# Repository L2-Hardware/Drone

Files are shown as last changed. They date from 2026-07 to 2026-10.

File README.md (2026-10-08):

# Drone

# Custom 5-Inch Quadcopter Project

Welcome to the main repository of our custom-built 5-inch FPV drone. This project is a collaborative effort to design, build, and program a high-performance quadcopter completely from scratch, bridging custom mechanical engineering with bespoke hardware and software design.

## Project Overview

Instead of relying on off-the-shelf Flight Controllers (FC) or pre-compiled firmware like Betaflight/ArduPilot, this project aims to build the core systems from the ground up to deeply understand drone flight dynamics, sensor fusion, and real-time embedded systems.

The project is divided into three main domains:
*   **Mechanics & Frame:** Custom 5-inch carbon fiber frame designed from scratch (designed by [Friend's Name]).
*   **Hardware (FC PCB):** A custom-designed Flight Controller board based on the STM32 architecture.
*   **Firmware (MCU):** A custom RTOS-based flight control software written in C/C++.

## System Architecture

*   **Power & Propulsion:** 6S LiPo Battery, custom 4-in-1 ESC (`Hardware/Kicad/ESCV00`, AM32 firmware), and 4x Brushless Motors (2207/2306).
*   **Radio Control:** custom ExpressLRS (ELRS) 2.4GHz receiver (`Hardware/Kicad/RXV00`, ESP32-C3 + SX1281) communicating via CRSF protocol for ultra-low latency.
*   **Video System (FPV):** custom analog 5.8GHz VTx (`Hardware/Kicad/VTXV00`, RTC6705 + RFPA5542) with on-board OSD (AT7456E) on the FC.
*   **Brain:** Custom STM32 Flight Controller (See `/Hardware` and `/Firmware` folders).

## Repository Structure

*   `/Mechanics` - 3D models, CAD files, and CNC routing paths for the frame.
*   `/Hardware` - KiCad projects: flight controller (FCV00), 4-in-1 ESC (ESCV00), ELRS receiver (RXV00), video transmitter (VTXV00).
*   `/Firmware` - STM32 source code, RTOS configuration, and PID algorithms.

## Status
*Active Development* - Currently designing the FC PCB and prototyping the RTOS task scheduler.

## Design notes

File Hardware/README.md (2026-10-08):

# Drone

# Custom Flight Controller PCB

This directory contains the KiCad projects for all the drone electronics, designed at chip level (no plug-and-play modules):

*   `Kicad/FCV00` - Flight Controller
*   `Kicad/ESCV00` - 4-in-1 ESC (AM32)
*   `Kicad/RXV00` - ExpressLRS 2.4 GHz receiver
*   `Kicad/VTXV00` - 5.8 GHz analog video transmitter

See `Kicad/Readme.md` for the block diagram, component choices, library installation and the list of items to verify before ordering boards.

The flight controller specifications are below.

## Hardware Specifications

*   **Form Factor:** 30.5 x 30.5 mm mounting pattern (Standard 5-inch stack).
*   **Microcontroller:** STM32F405RGT6 (168 MHz Cortex-M4F, 1 MB flash).
*   **IMU (Gyro/Accel):** TDK InvenSense ICM-42688-P on a dedicated **SPI1** bus with its own LDO and external 32 kHz CLKIN.
*   **Barometer:** ST LPS22DF (I2C1).
*   **Blackbox:** Winbond W25Q128JV 16 MB SPI flash (SPI3).
*   **OSD:** AT7456E chip on SPI2 for analog video telemetry overlay.
*   **Power Supply (BEC):** 
    *   Input: 6S LiPo (up to 25.2V).
    *   Step-down buck converters (TI TPS54360B, 60 V rated): 5V/3A (ELRS Rx, VTx, GPS, LEDs, USB) and 10V/2A (camera / HD VTx).
    *   3.3V: two AP2112K LDOs from 5V (one dedicated to the IMU).

## Pinout & Connectivity

The PCB is designed with the following I/O in mind:
*   **8-pin ESC Connector:** Carries GND, VBAT (Input), Current Sensor (ADC in), and 4x Motor Signals (DShot/PWM out).
*   **UART 1:** ExpressLRS Receiver (CRSF Protocol).
*   **UART 2 / SPI:** Video Transmitter (VTx) control / OSD.
*   **UART 3:** GPS / Compass (for future expansions).
*   **UART 4 / UART 5 TX:** AUX port.  **UART 5 RX:** ESC telemetry.
*   **USB-C:** configuration and DFU (BOOT button).
*   **I2C:** Reserved for external barometers or slow sensors.

## Design Considerations
*   **EMI Shielding:** The IMU is placed away from high-current ESC traces to minimize electromagnetic interference.
*   **Vibration Isolation:** The board must be mounted using rubber dampeners (gummies) to protect the gyro from motor noise.
*   **Decoupling:** Ample decoupling capacitors are placed near the STM32 and IMU to ensure clean power delivery.

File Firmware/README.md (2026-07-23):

# Drone

# Flight Controller Firmware

This directory contains the custom flight control software running on the STM32 microcontroller. The firmware is built around **FreeRTOS** to ensure strict deterministic execution of the critical flight loop while handling slower background tasks like telemetry and RC link parsing.

## Core Architecture (FreeRTOS)

To prevent communication protocols from blocking the flight stabilization, the firmware is divided into prioritized RTOS tasks:

1.  **High-Priority Flight Loop (1kHz - 4kHz):** 
    *   Reads IMU data via SPI.
    *   Applies Digital Low-Pass & Notch Filters to remove motor vibration noise.
    *   Computes Attitude Estimation (Mahony/Madgwick quaternion filters).
    *   Calculates the PID control output for Roll, Pitch, and Yaw.
    *   Mixes outputs and sends DShot commands to the 4-in-1 ESC.
2.  **Medium-Priority RC Task (250Hz / 500Hz):** 
    *   Parses incoming CRSF packets from the ExpressLRS receiver via UART.
    *   Maps stick inputs to desired angles/rates.
3.  **Low-Priority Telemetry & Video Task (10Hz):** 
    *   Reads battery voltage and current consumption.
    *   Sends record Start/Stop commands to the FPV camera.
    *   Updates OSD data.

## Flight Dynamics

*   **Attitude Estimation:** Fusing accelerometer and gyroscope data to calculate the drone's absolute orientation in 3D space.
*   **PID Controller:** Custom Proportional-Integral-Derivative loops tuned for 5-inch freestyle/racing dynamics.
*   **Motor Protocol:** Utilizing **DShot600** (Digital Shot) to send precise, noise-free throttle values to the ESC.

## Development Setup

*   **Toolchain:** GCC ARM Embedded / STM32CubeIDE.
*   **HAL:** STM32 Hardware Abstraction Layer (HAL) / LL drivers.
*   **RTOS:** FreeRTOS (CMSIS-V2).

### How to Build
1. Clone the repository.
2. Open the `.ioc` file in STM32CubeMX / STM32CubeIDE.
3. Generate code and compile using the standard ARM GCC toolchain.
4. Flash via ST-Link using SWD interface.

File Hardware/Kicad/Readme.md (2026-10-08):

# KiCad projects - drone electronics

## Libraries

All projects use the official library **[L2-Hardware/Kicad_Libs](https://github.com/L2-Hardware/Kicad_Libs)**
through the folder `Hardware/Kicad/KiCad_Libs` (ignored by git). The projects' `sym-lib-table` / `fp-lib-table`
point to `${KIPRJMOD}/../KiCad_Libs/<eLib>/...`.

Setup (once per PC):

```
cd C:\git\PCB
git clone https://github.com/L2-Hardware/Kicad_Libs.git      (-> C:\git\PCB\Kicad_Libs)
cd C:\git\PCB\Drone\Hardware\Kicad
bring_libs.bat                                                  (junction KiCad_Libs -> C:\git\PCB\Kicad_Libs)
```

### Adding new components: `KiCad_Libs_ToAdd/`

New parts that are not yet in the official library go into `KiCad_Libs_ToAdd/`, using the same layout
(`<eLib>/datasheet`, `<eLib>.3dshapes`, `<eLib>.pretty`, `<eLib>.kicad_sym` with only the new symbols).

1. `merge_libs.bat --clean`
   - appends the new symbols to `KiCad_Libs/<eLib>/<eLib>.kicad_sym` (a `.bak` is kept; existing names are skipped)
   - copies footprints, STEP models and datasheets (existing files are not overwritten, unless `--force`)
   - empties `KiCad_Libs_ToAdd` (only its README stays)
2. Open the touched libraries once in the Symbol Editor and save (upgrades them to your KiCad version),
   delete the `.bak` files, then commit + push in `C:\git\PCB\Kicad_Libs`.
3. Commit the emptied `KiCad_Libs_ToAdd` in this repo.

The schematics and PCBs embed their symbols and footprints, so they open even before the merge;
3D models (`${KIPRJMOD}/../KiCad_Libs/<eLib>/<eLib>.3dshapes/...`) show once the parts are in the official library.

Current content of `KiCad_Libs_ToAdd` (drone boards): footprints and 3D models from the official KiCad libraries,
symbols generated from the KiCad symbol pin tables where available, otherwise from the vendor datasheet
(those carry a `Verify` field). It also contains generic symbols (`R`, `C`, `L`, `LED`, power symbols ...):
if the official library already has symbols with the same names they are skipped by the merge.

## Boards

| Project | Board | Size / layers | Main parts |
|---|---|---|---|
| `FCV00` | Flight controller | 36x36 mm, 30.5 mm M3 pattern (4 mm holes for grommets), 4 layers | STM32F405RGT6, ICM-42688-P, LPS22DF, AT7456E OSD, W25Q128JV, 2x TPS54360B (5V 3A / 10V 2A), 2x AP2112K-3.3, USB-C |
| `ESCV00` | 4-in-1 ESC (AM32) | 42x42 mm, 30.5 mm M3 pattern, 6 layers 2 oz recommended | 4x (STM32F051K8U6 or AT32F421K8U7 + DRV8300D + 6x BSZ018N04LS6), 0.25 mOhm shunt + INA181A3, LMR16006 10V gate rail |
| `RXV00` | ExpressLRS 2.4 GHz receiver | 22x14 mm, 4 layers | ESP32-C3FH4 + SX1281, u.FL |
| `VTXV00` | 5.8 GHz analog VTX | 27x27 mm, 20x20 mm M2 pattern, 4 layers | RTC6705 + RFPA5542 (~25 dBm), STM32F031G6U6 / GD32F130G6U6 (OpenVTx) |

```
 6S LiPo ──XT60──► ESCV00 ──(JST-SH 8: VBAT GND CURR TLM M1..M4)──► FCV00 ──(JST-SH 4: 5V GND TX RX)──► RXV00 ── 2.4 GHz antenna
                   │  4x BLDC motors                                  │  ├─(JST-SH 6: 10V 5V GND VIDEO TX RX)──► VTXV00 ── 5.8 GHz antenna
                   └──────────────────────────────────────────────────┘  ├─(JST-SH 3: PWR GND VIDEO)◄── analog FPV camera (bought)
                                                                         ├─ GPS / compass port, AUX UART port, LED strip, buzzer
                                                                         └─ USB-C (configuration / DFU)
```

The connectors are pin-matched, so the harnesses are 1:1 JST-SH cables. Power the FC from the ESC harness only,
not from separate battery wires. Otherwise part of the motor return current flows through the JST ground wire
and bypasses the current shunt.

Bought parts that are not designed here: motors, battery, camera, propellers, antennas, frame.

### Each project contains
* `<NAME>.kicad_sch` - hierarchical schematic (root page = overview + design notes, one sub-sheet per block)
* `<NAME>.kicad_pcb` - board outline, mounting holes, layer count, GND plane on In1, every footprint loaded with
  its nets and linked to its symbol (footprints are parked next to the outline, grouped by sheet)
* `<NAME>.kicad_pro` - net classes (power / gate / RF 50 ohm / USB ...) and JLCPCB-compatible minimum rules
* `<NAME>_BOM.csv` - grouped BOM with manufacturer part numbers for the active parts
* `RXV00/RXV00_hardware.json` - ExpressLRS hardware layout for the receiver

## Validation done
* Every schematic was exported with `kicad-cli`. KiCad's connectivity matches the intended netlist exactly (no
  merged or split nets).
* Every symbol pin maps to a footprint pad. Every footprint pad that needs a net has one.
* All symbol libraries load in KiCad.
* Files are written in the KiCad 7 format. KiCad 8/9 open them and upgrade them on save. Run ERC in KiCad once
  after opening: the KiCad 7 command line has no ERC.

## Verify before ordering boards
Parts whose pin table was typed from a datasheet carry a `Verify` field. Check them against the latest datasheet:

| Part | What to check |
|---|---|
| AT7456E | Uses the MAX7456 pinout. Check the HTSSOP exposed-pad size. |
| SX1281 | Pin table from Semtech DS rev 3.x. RF matching values are starting points (tune with a VNA). |
| RTC6705 | Pin table from `datasheet/RTC6705-RichWave.pdf`. The exposed-pad size is not given (QFN-40 6x6, EP 4.6 assumed). Loop filter, output match and the BUFVDD power-control path are starting points. |
| DRV8300DRGER | Pin table from the TI datasheet. Check the RGE exposed-pad size. |
| ICM-42688-P | Pin table from the KiCad IIM-42652 symbol (same LGA-14 package). Check the RESV pins. |
| BSZ018N04LS6 | NexFET SON3.3 land pattern reused. Compare with Infineon's PG-TSDSON-8 FL footprint. |
| TPS54360B | The compensation network is a starting point. Run TI WEBENCH for the final values. |

Passive, crystal and LED part numbers are suggestions: confirm them (stock, load capacitance, voltage rating) at
your distributor or assembler.

## Next steps
1. Merge `KiCad_Libs_ToAdd` into the official library (above), open each project, run ERC.
2. PCB: place the parts (connectors on the edges, IMU away from the bucks, short power loops), then route.
   Use 50 ohm coplanar lines on RXV00/VTXV00 and a full GND plane under the RF parts. On ESCV00, use wide
   polygons for VBAT/phases and thermal vias. Run DRC.
3. Order from JLCPCB / PCBWay: gerbers + BOM + placement file, assembly (ESC 6 layers 2 oz).
4. Bring-up order: power rails, then SWD/DFU, then each sensor, then radio links.

## Firmware notes
* **FCV00**: pin map on the root sheet (gyro SPI1 + external 32 kHz CLKIN on PB0, OSD SPI2, flash SPI3,
  motors TIM8 CH1-4 on PC6-PC9).
* **ESCV00**: AM32. With F051, use `HARDWARE_GROUP_F0_B`. With AT32F421, use `HARDWARE_GROUP_AT_B` +
  `HARDWARE_GROUP_AT_045` (same pinout as `TBS_6S_4IN1_F421`). Flash the bootloader per MCU through the SWD pads
  once.
* **RXV00**: ExpressLRS `Unified_ESP32C3_2400_RX` + `RXV00_hardware.json` (based on "Generic C3 2400").
* **VTXV00**: OpenVTx `Generic_GD32F130` pinout (populate GD32F130G6U6), or your own firmware on the STM32F031.
  Up to 25 mW EIRP is licence-free in the EU. Higher power needs an amateur radio licence.

## Regenerating
`tools/gen/` holds the scripts that produced the `KiCad_Libs_ToAdd` parts, schematics, BOMs and PCB set-up:
`build.py` (libraries + schematics + BOM), `check.py` (connectivity check) and `pcbgen.py` (PCB set-up).
**Re-running them overwrites the project files.** They are a starting point: once you start editing in KiCad,
KiCad is the master.

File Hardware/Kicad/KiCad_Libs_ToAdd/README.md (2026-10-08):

# KiCad_Libs_ToAdd

Inbox for new components that are not yet in the official library
([L2-Hardware/Kicad_Libs](https://github.com/L2-Hardware/Kicad_Libs)).

Same layout as the official library:

```
<eLib>/
    datasheet/
    <eLib>.3dshapes/
    <eLib>.pretty/
    <eLib>.kicad_sym      only the new symbols
    .gitignore
```

Workflow:
1. `bring_libs.bat` (once): junction `KiCad_Libs` -> `C:\git\PCB\Kicad_Libs`
2. `merge_libs.bat --clean`: merges everything here into the official library and empties this folder
3. Open the touched libraries in the Symbol Editor, save, then commit + push in the `Kicad_Libs` repo
4. Commit the (now empty) `KiCad_Libs_ToAdd` here

Usually this folder is empty (only this README).

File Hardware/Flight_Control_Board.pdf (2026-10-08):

## Flight Controller Board HARDWARE ARCHITECTURE

Lorenzo Bartalucci

1

1 INTRODUCTION

### 1 Introduction

### 1.1 Purpose and Scope

This document defines the hardware architecture, component selection rationale, power distribution network (PDN) design, signal integrity (SI) rules, RF subsystem design, electromagnetic compatibility (EMC) strategy, mechanical/DFM constraints, and verification plan for the HRO-FC1 — a custom flight controller (FC) intended for a multirotor aerial observation platform requiring simultaneous 4 K on-board video recording and low-latency analog FPV downlink with remote camera tilt control.

This specification is the authoritative reference for PCB layout, component procurement, and verification test planning. It supersedes the informal concept notes captured in Rev. A.

### 1.2 Applicable Documents and Standards

- IPC-2221 — Generic Standard on Printed Board Design
- IPC-2141A — Design Guide for High-Speed Controlled Impedance Circuit Boards
- IPC-6012 — Qualification and Performance Specification for Rigid PCBs (Class 2 target, Class 3 workmanship where noted)
- IPC-A-610 — Acceptability of Electronic Assemblies
- FCC Part 15, Subpart C (§15.247 / §15.249) — Intentional radiators, 5.725–5.875 GHz ISM band
- ETSI EN 300 440 — Short-range devices, 5.8 GHz band (EU applicability)
- MIL-STD-810H, Method 514.8 — Vibration (Category 24, rotary-wing platform, as guidance only; full military qualification is out of scope)
- RTCA DO-160 (referenced for environmental test methodology guidance only; full DO-160 qualification not required for this program)

### 1.3 Definitions and Acronyms

Term | Definition
FC | Flight Controller
PDN | Power Distribution Network
PDS | Power Distribution System (synonymous with PDN in this document)
SI | Signal Integrity
CPWG | Coplanar Waveguide with Ground
VTx | Video Transmitter (analog, 5.8 GHz)
PA | Power Amplifier
IMU | Inertial Measurement Unit
CVBS | Composite Video Baseband Signal (analog composite video)
DFM/DFA | Design for Manufacturing / Design for Assembly
FMEA | Failure Modes and Effects Analysis
EIRP | Effective Isotropic Radiated Power
ESR/ESL | Equivalent Series Resistance / Equivalent Series Inductance

### 1.4 Mission Profile / Concept of Operations

The vehicle is a hexacopter observation platform performing loiter/hover observation at 30 m to 120 m AGL for missions up to 25 minutes on 6S LiPo. The system must simultaneously: (a) record 4 K @ 30 fps to onboard storage for post-mission analysis, (b) provide a real-time analog FPV downlink to the ground pilot/observer for situational awareness, and (c) allow the observer to remotely pitch the camera between −90◦

(nadir) and +30◦
from level. Altitude hold via barometer

1 INTRODUCTION

and GPS position hold are required to keep the platform stable while the observer manually operates the gimbal, decoupling flight control workload from camera aiming workload.

### 2 System Requirements

Requirements are numbered for traceability into the Verification Matrix (Section 13). “Shall” denotes a mandatory, testable requirement; “should” denotes a goal.

### 2.1 Functional Requirements

ID | Requirement
REQ- CAM-001 | The system shall record video at 4 K (3840×2160) at 30 fps to remov- able Micro SD storage, U3/V30 rated, up to 128 GB.
REQ- CAM-002 | The system shall provide a simultaneous real-time analog CVBS output (NTSC or PAL, field-selectable) for the FPV downlink, independent of the SD recording pipeline.
REQ- CAM-003 | The FC shall be able to start/stop SD card recording via a UART command link to the camera module, triggered by a radio control (RC) auxiliary channel.
REQ- GIM-001 | The FC shall generate a servo-compatible PWM signal (50 Hz nominal, 1000 µs to 2000 µs pulse width) on a hardware timer channel to actuate a camera tilt servo across a minimum mechanical range of 120◦
REQ- GIM-002 | Loss of RC signal shall command the gimbal to a pre-configured safe position (default: level, 0
◦
) within 500 ms of failsafe detection.
REQ- VTX-001 | The onboard VTx shall be tunable in firmware across the standard 5.8 GHz analog FPV band plan (Section 9) via SPI, with the active channel persisted in non-volatile memory.
REQ- VTX-002 | The VTx output power shall be configurable to at least three discrete levels (nominal targets: 25 mW, 200 mW, 400 mW) to support regional regulatory compliance.
REQ- NAV-001 | The FC shall maintain barometric altitude hold to within ±0.5 m in still air and provide GPS-based position hold to within ±1.5 m horizontal (with ≥8 satellites, HDOP < 1.5).
REQ- NAV-002 | Compass (magnetometer) heading accuracy shall be within ±5
- post-
| calibration, with the module physically separated from high-current conductors per Section 10.

### 2.2 Performance Requirements

ID | Requirement
REQ- PERF-001 | Glass-to-glass analog FPV latency shall not exceed 80 ms (camera sen- sor to ground-station display), excluding goggle/receiver processing.
REQ- PERF-002 | IMU sampling rate shall be ≥6.4 kHz raw, with attitude control loop closure at ≥2 kHz to support stable hover in gusts up to 8 m/s.
REQ- PERF-003 | VTx analog video downlink range (line-of-sight, 400 mW, standard patch/omni antenna) shall achieve ≥2 km at ≤−85 dBm receiver sen- sitivity margin of 6 dB.

2.3 Environmental Requirements | 1 INTRODUCTION
ID | Requirement
REQ- PERF-004 | Total continuous current draw of the FC/camera/VTx/gimbal subsys- tem (excluding motors/ESCs) shall not exceed 3.0 A at 5 V, per the power budget in Table 11.

### 2.3 Environmental Requirements

ID | Requirement
REQ- ENV-001 | Operating temperature range: −10◦C to +45◦C ambient; storage −20◦C to +60◦C.
REQ- ENV-002 | The PCB assembly shall withstand random vibration per MIL-STD- 810H Method 514.8, Category 24 (rotary-wing, general), 7.7 grms, 10 Hz to 2000 Hz, without component detachment or solder joint fatigue over a 2-hour per-axis test.
REQ- ENV-003 | The assembly shall tolerate humidity up to 95% RH non-condensing; conformal coating is required per Section 11.
REQ- ENV-004 | Operating altitude up to 4000 m MSL (derate convective cooling as- sumptions accordingly, see Section 6.3).

### 2.4 EMC / Regulatory Requirements

ID | Requirement
REQ- EMC-001 | The VTx intentional radiator shall comply with FCC Part 15.247 (or region-appropriate equivalent, e.g., ETSI EN 300 440) for the target market at the configured output power level.
REQ- EMC-002 | Radiated/conducted emissions from the RF section shall not desen- sitize the IMU, barometer, GPS L1 front-end (1575.42 MHz), or the analog CVBS trace by more than 1 dB / 1 LSB equivalent noise floor increase, verified per Section 10.
REQ- EMC-003 | Regulatory caution: 400 mW EIRP exceeds unlicensed limits in sev- eral jurisdictions (e.g., EU 25 mW under ETSI EN 300 440 for non- amateur use). The design shall default to the lowest legal power level in firmware and require explicit user configuration to enable higher power modes, with an on-screen/telemetry regulatory disclaimer.

### 2.5 Safety Requirements

ID | Requirement

REQ-SAF-

001 | Input power path shall include reverse-polarity protection, input fus- ing/current limiting, and inrush current limiting for hot-plug of a charged 6S pack (Section 6).

REQ-SAF-

002 | The MCU shall monitor input bus voltage and enter a low-power/land- now telemetry state below 19.8 V (3.3 V/cell) to protect the LiPo pack.

REQ-SAF-

003 | Thermal protection: firmware shall throttle or disable the VTx PA if the PA case temperature (via NTC or PA internal flag) exceeds 95◦C.

4 CAMERA & GIMBAL SUBSYSTEM DESIGN

### 3 System Architecture Overview

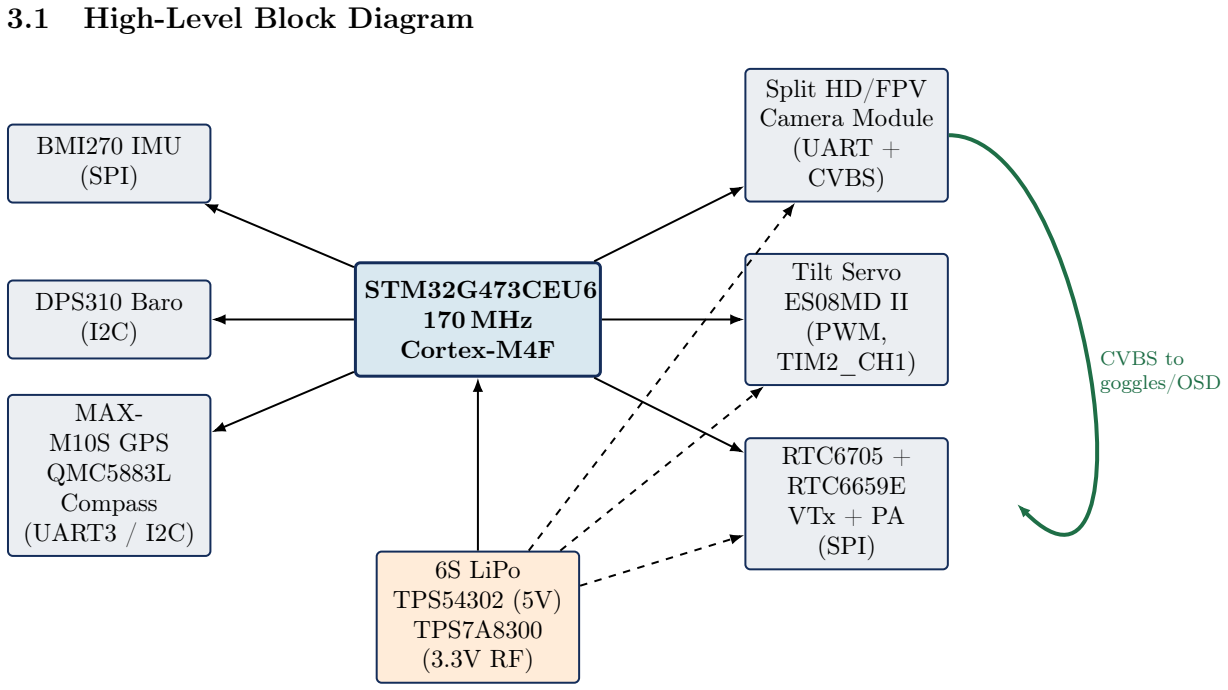
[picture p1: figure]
3.1 High-Level Block Diagram; STM32G473CEU6 170 MHz Cortex-M4F; BMI270 IMU (SPI); DPS310 Baro (I2C); MAX- M10S GPS QMC5883L Compass (UART3 / I2C); Split HD/FPV Camera Module (UART + CVBS); Tilt Servo ES08MD II (PWM, TIM2_CH1); RTC6705 + RTC6659E VTx + PA (SPI); 6S LiPo TPS54302 (5V) TPS7A8300 (3.3V RF); CVBS to goggles/OSD

Figure 1: HRO-FC1 top-level hardware block diagram. Solid arrows: control/data signals. Dashed arrows: power rails. Green: analog video signal path, isolated from the digital control path per Section 10.

### 3.2 Interface Control Summary

### 4 Camera & Gimbal Subsystem Design

### 4.1 Camera Selection Rationale

A split-style HD/FPV camera decouples 4 K ISP/encode workload from the flight-critical STM32, which only needs to arbitrate a UART control link and, optionally, overlay OSD data onto the CVBS path. This avoids adding an application-processor-class SoC (and its associated Linux/RTOS complexity, boot time, and thermal load) to a safety-relevant flight control board.

Design Note — SD Card Selection: Micro SD cards shall be U3/V30 (or A2 where the camera ISP supports it) rated to sustain the ≥30 MB/s minimum write throughput required for stable 4 K@30 H.264/H.265 encoding without frame drops. Industrial-temperature-rated cards (rated to at least the −10◦C to +45◦C operating range of REQ-ENV-001) are recommended over consumer-grade cards, which are frequently only rated to 0

◦C at the low end.

### 4.2 Gimbal Torque Budget

The tilt servo must overcome the gravitational moment of the camera/lens assembly about the tilt axis plus dynamic (vibration/maneuvering) loads. A first-order sizing calculation:

Assumed camera + mount mass, m = 25 g = 0.025 kg
Moment arm (CG offset from tilt axis), r = 20 mm = 0.02 m Static gravitational torque, τg = m · g · r = 0.025 × 9.81 × 0.02 ≈ 4.9 × 10⁻³ N · m ≈ 0.05 kg · cm

4.3 Edge Cases and Fault Handling | 4 CAMERA & GIMBAL SUBSYSTEM DESIGN
Interface | Peripheral | Electrical | Notes
IMU | BMI270 | SPI1, 3.3 V, up to 10 MHz | Dedicated CS,
| | | no bus sharing
| | | with RTC6705
Barometer | DPS310 | I2C1, 3.3 V, 400 kHz | Shares I2C bus
| | | with compass
| | | (different
| | | addresses)
GPS | MAX-M10S | UART3, 3.3 V, 115200 bps (config) | PPS input to
| | | MCU timer
| | | capture for time
| | | sync
Compass | QMC5883L | I2C1, 3.3 V, 400 kHz | Located ≥25 mm
| | | from
| | | PA/inductors
| | | (Section 10)
Camera control | RunCam Split 4 V3 | UART2, 3.3 V TTL, 115200 bps | RunCam Device
| | | Protocol
| | | (start/stop rec,
| | | OSD, mode)
Camera video | RunCam Split 4 V3 | CVBS, 1 Vpp into 75 Ω | Routed as
| | | controlled-
| | | impedance
| | | analog trace to
| | | VTx and to an
| | | external
| | | OSD/goggle
| | | pigtail
Gimbal servo | EMAX ES08MD II | PWM, TIM2_CH1, 3.3 V logic / 5 V supply | Update rate
| | | 50 Hz, resolution
| | | ≥ 10-bit
| | | equivalent
VTx control | RTC6705 | SPI2, 3.3 V, ≤1 MHz | Register-based
| | | PLL frequency +
| | | power level set
Battery sense | — | Analog, resistor-divided to ≤3.3 V | ADC1, hardware
| | | low-pass at 10 Hz

Table 7: Interface Control Document (ICD) summary. Full pin mapping in Appendix A.

Adding a dynamic safety factor of 6× (to cover angular acceleration during rapid tilt commands, in-flight vibration coupling, and worst-case CG offset with an accessory such as an IR filter or larger lens) gives a required stall torque of approximately 0.3 kg · cm. The specified EMAX ES08MD II (rated ∼2.0 kg cm at 4.8 V) provides a design margin in excess of 6× over this budget, which comfortably covers gust-induced disturbance torques not captured in the first-order model above.

Design Note — Servo Refresh Rate vs. Control Loop: The gimbal PWM update (50 Hz) is intentionally decoupled from the 2 kHz+ attitude control loop (REQ-PERF-002). The MCU shall write the target pulse width into a double-buffered compare register (TIM2_CH1 CCR, using the timer’s preload feature) so that updates take effect only at the next PWM period boundary, preventing partial-pulse glitches that could cause servo jitter.

### 4.3 Edge Cases and Fault Handling

4.3 Edge Cases and Fault Handling | 4 CAMERA & GIMBAL SUBSYSTEM DESIGN
Candidate | 4K Recording | Analog Latency | Notes
RunCam Split 4 V3 (baseline) | 4K@30, 2.7K@60 | ∼40 ms typical | Mature UART
| | | control protocol
| | | (RunCam Device
| | | Protocol); wide
| | | community/firmware
| | | support.
Caddx Loris 4K | 4K@30, 4K@60
| (HFR) | ∼45–50 ms | Higher headline
| | | resolution/frame-
| | | rate options; verify
| | | UART control
| | | command set parity
| | | before substitution.
Foxeer Mix 2 | 4K@30 | ∼40 ms | Similar form factor;
| | | alternate second
| | | source.

Table 8: Camera module trade study. RunCam Split 4 V3 selected as primary; Caddx Loris 4K retained as approved alternate pending UART command-set validation.

Edge Case | Required Handling
SD card full | Camera module shall report status via UART telemetry (RunCam Device Protocol status field); FC shall raise an
| OSD/telemetry warning at ≥90% capacity and on write
| failure. Recording of flight-critical telemetry (if overlaid)
| must not depend on SD card health.
SD card write corruption on power loss
| A minimum 470 µF (bulk, Section 6) plus internal camera-
| module hold-up capacitance must sustain the camera’s 3.3 V/5 V rail for ≥50 ms after main bus brown-out to allow
| the camera’s internal file system to close the current video segment/finalize the container (MP4 moov atom). This
| shall be validated per test VER-PWR-03.
Camera module brown-out / no ACK on UART
| FC firmware shall implement a 3-retry UART handshake
| with 200 ms timeout before flagging a CAM_FAULT sta-
| tus; VTx CVBS path is unaffected since it is a separate
| analog output not gated by UART link health.
Servo mechanical stall
(ice, physical obstruction, wiring snag)
| FC shall monitor servo supply current via a low-side shunt
| on the dedicated servo rail; sustained current >1.2 A for
| >200 ms shall trigger a GIMBAL_STALL flag and com-
| mand PWM to the neutral position to avoid burning out
| the servo winding.
RC link loss during active tilt command
| Per REQ-GIM-002, revert to configured safe position
| within 500 ms; do not freeze at last commanded angle, since an extreme nadir/zenith angle could obstruct antenna line-
| of-sight to the VTx patch antenna.
Sustained | 4K@30
recording | thermal
throttle | Camera modules are known to throttle bitrate/frame rate
| after ∼10–15 minutes of continuous 4K recording in en-
| closed housings. Provide a minimum 3 mm ventilation gap
| or thermal pad from the camera processing board to the
| airframe shell; this is a mechanical integration note for the vehicle housing design, tracked as open item OPEN-01 (Sec-
| tion 15).

6 POWER ARCHITECTURE & POWER INTEGRITY (PI)

### 5 Bill of Materials & Component Selection

Subsystem | Part Number | Mfr. | Package | Role / Selection Rationale
MCU | STM32G473CEU6 | STMicro. | UFQFPN48 | 170 MHz Cortex-M4F, FPU + CORDIC +
| | | | FMAC, 6× 16-bit advanced timers for
| | | | PWM/servo/ESC generation, hardware CRC
| | | | for SD/telemetry integrity checks.
IMU | BMI270 | Bosch | LGA-14 | Best-in-class vibration rejection (on-chip
| | | | anti-aliasing, low-power high-performance
| | | | modes); SPI up to 10 MHz.
Barometer | DPS310 | Infineon | LGA-8 | High resolution (±0.06 hPa RMS), low
| | | | temperature coefficient, I2C/SPI selectable.
GPS | MAX-M10S | u-blox | LGA-18 | Multi-constellation
| | | | (GPS/GLONASS/Galileo/BeiDou), integrated
| | | | 10 Hz nav solution, dedicated PPS output.
Compass | QMC5883L | QST | LGA-16 | Low-cost 3-axis magnetometer; must be
| | | | physically separated from ESC/PA current
| | | | loops – see Section 10.
VTx core | RTC6705 | RichWave | QFN-32 | Integrated 5.8 GHz FM modulator/PLL
| | | | synthesizer, SPI-programmable channel and
| | | | power.
RF PA | RTC6659E | RichWave | QFN-16 | Boosts RTC6705 output to ∼400 mW EIRP
| | | | class; requires dedicated thermal via array
| | | | (Section 11).
Main buck | TPS54302DDCR | TI | SOT23-
| | | thin/SON-8

Steps 6S (19.8–25.2 V) to 5 V/3 A for camera,
| | | | servo, digital rail source.
RF LDO | TPS7A8300ARGR | TI | VQFN-20 | Ultra-low-noise (9 µVrms typ.), high PSRR
| | | | LDO for RTC6705/PA analog supply.
Digital LDO | (TBD, | e.g.,
| TLV75533)
TI | (pro-
| | posed) | SOT23-5 | Dedicated 3.3 V rail for MCU/IMU/baro/GPS,
| | | | isolated from RF and servo transients; open
| | | | selection, see OPEN-02.
Gimbal servo | ES08MD II | EMAX | — | 9 g metal-gear digital servo, ∼2.0 kg cm stall
| | | | torque at 4.8 V (see Section 4.2 torque budget).
Camera | mod-
ule | RunCam Split 4 V3 | RunCam | — | Split lens/processing architecture; 4K@30 SD
| | | | recording + CVBS output + UART control
| | | | (Section 4.1).

Table 10: Bill of Materials – key active components. Passive component BOM (decoupling, filtering) is enumerated in Table 12. Full BOM with distributor part numbers, unit cost, and lead time is maintained in the companion procurement spreadsheet (out of scope for this document).

△ Caution — Second-Sourcing: The RTC6705/RTC6659E pairing and the TPS7A8300 are specified as single-source in this revision. Given global passive/RF-IC supply volatility, a second-source RF chipset (e.g., IRC Tramp-compatible modules) should be evaluated before committing to tooling; this is tracked as OPEN-03.

### 6 Power Architecture & Power Integrity (PI)

### 6.1 Power Budget

### 6.2 Power Tree

### 6.3 Buck Converter Design (TPS54302, 5 V/3 A)

Assume a representative switching frequency fsw = 570 kHz (typical of this converter class) and a target inductor ripple current of 30% of full load (∆IL = 0.9 A):

L =

(Vin,max − Vout) · Vout

Vin,max · fsw · ∆IL

=

(25.2 − 5.0) × 5.0
25.2 × 570,000 × 0.9

≈ 7.8 µH

A standard 10 µH, shielded-drum inductor rated ≥4.5 Asat is selected to provide margin. Duty cycle at nominal/extreme input:

Dnom =

5.0
22.2

≈ 22.5%, Dmin,V in =

5.0
25.2

≈ 19.8%, Dmax,V in =

5.0
19.8

≈ 25.3%

6.4 PDN Target Impedance | 6 POWER ARCHITECTURE & POWER INTEGRITY (PI)
Load | Rail | Typ. I | Max. I | Typ. P | Max. P
STM32G473 (core+IO) | 3.3 VDIG | 80 mA | 150 mA | 0.26W | 0.50W
BMI270 + DPS310 | 3.3 VDIG | 5 mA | 10 mA | 0.02W | 0.03W
MAX-M10S GPS | 3.3 VDIG | 25 mA | 40 mA | 0.08W | 0.13W
QMC5883L | 3.3 VDIG | 1 mA | 2 mA | <0.01W | 0.01W
Camera module | 5 V | 400 mA | 800 mA | 2.0W | 4.0W
Gimbal servo (ES08MD II) | 5 V | 150 mA | 1500 mA (stall) | 0.75W | 7.5W (transient)
RTC6705 core | 3.3 VRF | 150 mA | 200 mA | 0.50W | 0.66W
RTC6659E PA (400 mW mode) | 5 VRF | 350 mA | 500 mA | 1.75W | 2.5W
Total (5 V rail) | 5 V | 900 mA | 2.8 A | 4.5W | 14.0W (transient)
Total (3.3 VDIG) | 3.3 V | 111 mA | 202 mA | 0.37W | 0.67W

Table 11: System power budget. The 3 A continuous rating of the TPS54302 buck (REQ-PERF-004) provides margin over the 0.9 A typical/2.8 A transient 5 V load; servo stall and PA keying transients are handled by bulk capacitance (Section 6.4), not by continuous buck current capability.

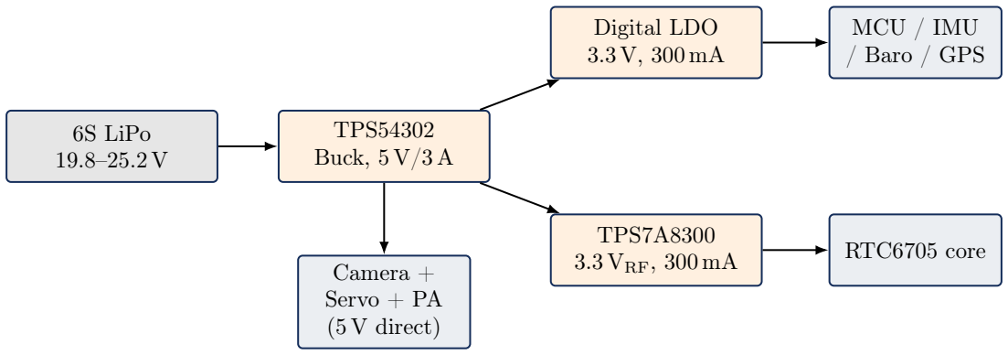
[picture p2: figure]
6S LiPo 19.8–25.2 V; TPS54302 Buck, 5 V/3 A; Digital LDO 3.3 V, 300 mA; TPS7A8300 3.3 VRF, 300 mA; MCU / IMU / Baro / GPS; RTC6705 core; Camera + Servo + PA (5 V direct)

Figure 2: Power tree. Three isolated regulation domains from a single buck pre-regulator: (1) 5 V direct for high-current/noisy loads (camera, servo, PA), (2) 3.3 VDIG for MCU/sensor logic via a quiet digital LDO, (3) 3.3 VRF via ultra-low-noise TPS7A8300 exclusively for the RTC6705 synthesizer core.

Output ripple voltage budget of 50 mV implies a maximum combined capacitor ESR:

ESRmax =

∆Vripple
∆IL

=

0.05
0.9

≈ 55 mΩ

This is satisfied by a parallel combination of ceramic (bulk high-frequency, low ESL) and polymer/electrolytic (bulk energy storage) capacitance – see Section 6.4.

Design Note — Efficiency and Thermal Derating: At Iout = 2.8 A transient and Vin = 22.2 V, converter losses (conduction + switching, estimated at ∼8–10% for this converter class at this duty cycle) yield an estimated dissipation of 1.0–1.4 W in the regulator package. With no forced airflow at 4000 m MSL (REQ-ENV-004, reduced convective cooling), the PCB copper pour under/around the IC exposed pad must provide θJA ≤ 40 ◦C/W to stay within the junction temperature budget at 45◦C ambient. This shall be confirmed by thermal simulation and bench thermal imaging (VER-PWR-04).

### 6.4 PDN Target Impedance

Using the target impedance method (Ohm’s law applied to the worst-case transient step and allowable ripple budget):

Ztarget =

VDD × ripple%

∆Itransient

6.5 Decoupling Strategy | 6 POWER ARCHITECTURE & POWER INTEGRITY (PI)

For the 3.3 VDIG rail, assuming a 3% ripple budget and a 300 mA transient step (SPI burst + IMU wake):

Ztarget,DIG =

3.3 × 0.03
0.3

= 0.33 Ω

This target is straightforward to meet with standard MLCC decoupling (Table 12) and does not require an embedded-capacitance layer. The RF rail (3.3 VRF) is instead governed by noise floor (PSRR of the TPS7A8300 at the switching frequency of the upstream buck and its harmonics) rather than target impedance alone, since the RTC6705 phase noise is directly modulated by supply noise.

### 6.5 Decoupling Strategy

Location | Value | Package | Purpose

STM32 VDD pins
(each)
100 nF | 0402 | High-frequency local decoupling, <2 mm from pin
STM32 VDDA | 100 nF + 1 µF | 0402/0603 | Analog supply, star-connected, ferrite bead from
VDD
BMI270
VDD/VDDIO
100 nF (each) | 0402 | Placed on the component side, direct via to GND
plane
Buck output (bulk) | 22 µF | × | 2
(ceramic,
X7R/X6S)
0805 | Low-ESL bulk, close to inductor output

Buck output (bulk,
electrolytic)

100 µF polymer SMD case
D

Damps load-transient droop

Servo header (dedicated)

470 µF electrolytic

Radial
SMD

Absorbs stall-current spikes, see Section 6.6

RTC6705/PA rail | 100 nF + 10 nF
+ | 1 nF | (stag-
gered)
0402 | Broadband decoupling across MHz–GHz range

Table 12: Decoupling capacitor placement and sizing strategy.

### 6.6 Servo Bulk Capacitance / Hold-Up Sizing

The buck converter’s control loop bandwidth is typically 1/10th to 1/5th of fsw, giving an effective transient response time on the order of t ≈ 50 µs before the loop can react to a step load. Sizing the bulk capacitor to hold the rail within a 200 mV droop budget during a 1.5 A servo-stall current step:

C =

I · t
∆V

=

1.5 × 50 × 10⁻⁶

0.2

= 375 µF

The specified 470 µF electrolytic provides ∼25% margin over this first-order estimate. This capacitor must be physically located at the servo connector, not solely at the buck output, since PCB trace/connector inductance (∼1–5 nH/mm) will otherwise dominate the transient impedance seen by the servo.

### 6.7 RF Supply Isolation

The RTC6705 and RTC6659E PA shall not share a regulator, plane region, or return path with the servo or camera 5 V loads. The TPS7A8300 (PSRR typ. 60 dB at 1 MHz, derating at higher frequencies) is dedicated solely to the RTC6705 synthesizer core; the PA itself, being a saturated/nonlinear stage, is comparatively tolerant of supply noise but shall still be fed through a ferrite-bead + local bulk/decoupling pi-filter from the main 5 V rail to prevent PA-generated switching noise (from RF envelope keying) from injecting back into the shared 5 V domain and desensitizing the camera’s analog CVBS output.

6.8 Input Protection | 7 PCB STACKUP & LAYER DEFINITION

### 6.8 Input Protection

- Reverse polarity: P-channel MOSFET high-side protection (preferred over a series diode to avoid I

2R loss at 2.8 A) or an ideal-diode controller IC.
- Overcurrent / short-circuit: Input fuse or PTC resettable fuse sized at 1.5× max steadystate current (∼4.2 A rating for a 2.8 A load).
- Inrush limiting: NTC thermistor or MOSFET soft-start controller to limit inrush when hot-plugging a charged 6S pack into discharged input capacitance, preventing connector arcing/pitting.
- Transient suppression: TVS diode (e.g., SMBJ30A class, selected for standoff voltage above 25.2 V max pack voltage) across the input bus for motor/ESC-induced transients coupled back through the power distribution board.

### 7 PCB Stackup & Layer Definition

### 7.1 Stackup Table

A 6-layer stackup is mandatory to provide a continuous ground reference beneath both the high-speed SPI/digital signals and the 5.8 GHz RF trace, while allowing a dedicated power plane to keep PDN inductance low.

Layer Function | Material | Thickness | Cu Wt.
L1 | Signal | (components,
RF island)
| | — | — | 1 oz
| | | | (35 µm)
— | Prepreg | Isola 370HR, 2116, εr ≈
| | 4.2 @ 1 GHz | 0.10 mm (4 mil) | —
L2 | GND (solid reference
| plane) | — | — | 1 oz
— | Core | Isola 370HR, εr ≈ 4.2 | 0.20 mm | —
L3 | Power (5 V / 3.3 V split
| pour) | — | — | 1 oz
— | Core | Isola 370HR, εr ≈ 4.2 | 0.71 mm (core, adjust
| | | for target thickness) | —
L4 | Signal (SPI, UART,
| PWM) | — | — | 1 oz
— | Prepreg | Isola 370HR, 2116 | 0.10 mm (4 mil) | —
L5 | GND (solid reference
| plane) | — | — | 1 oz
— | Core | Isola 370HR | 0.20 mm | —
L6 | Signal (bottom, low-
| speed / silkscreen side) | — | — | 1 oz

Table 13: 6-layer stackup definition. Laminate specified as Isola 370HR (mid-Tg, well-characterized, cost-effective) for the digital stack. Loss budget note: the RF trace on L1 is short (<15 mm from RTC6659E to the U.FL connector); at this length, standard FR4-class loss (∼0.35–0.45 dB/cm at 5.8 GHz) is acceptable (<0.7 dB total insertion loss) and does not justify the cost/lead-time penalty of a hybrid Rogers RO4350B cap layer for this program. This assumption shall be re-verified if the RF trace length grows beyond ∼25 mm in final layout.

△ Caution — Fabricator Variation: Dielectric constant and thickness tolerances vary between fabricators and even between panel lots. The exact laminate opening (resin content, glass style) for each dielectric shall be called out explicitly in the fab drawing rather than left to the fabricator’s standard stackup, and impedance-controlled layers shall be called out with a ±10% impedance tolerance requirement, verified by fabricator-supplied coupon TDR measurement per lot (Section 13).

7.2 Controlled Impedance Targets | 8 SIGNAL INTEGRITY & LAYOUT RULES

### 7.2 Controlled Impedance Targets

Net Class | Topology | Target Z0 | Reference Layer
SPI | (IMU, | VTx,
generic)
Single-ended microstrip | 50 Ω ±10% | L2 (solid GND)
UART (camera, GPS) | Single-ended microstrip | 50 Ω | ±10%
(relaxed, | low-
speed)

L2

CVBS analog video | Single-ended microstrip | 75 Ω ±10% | L2
5.8 GHz RF (PA to an- tenna) | CPWG | 50 Ω ±5% | L2, plus coplanar ground pour on L1

Table 14: Impedance targets by net class. Note the CVBS video path is 75 Ω per composite video convention, distinct from the 50 Ω digital/RF targets – do not apply a blanket 50 Ω rule to the analog video trace.

### 8 Signal Integrity & Layout Rules

### 8.1 General Principles

Reflections arise from impedance discontinuities: changes in trace geometry, layer transitions without adjacent return-path stitching, connector transitions, and unterminated stubs. The single most effective SI control is maintaining a solid, unbroken reference plane directly beneath every high-speed or RF trace – this is non-negotiable for the SPI buses and the 5.8 GHz RF trace alike.

### 8.2 Digital Trace Rules (SPI / UART / PWM)

- Route SPI point-to-point (STM32 ↔ BMI270, STM32 ↔ RTC6705); no daisy-chaining, no stubs off the main line.
- Rule-of-thumb maximum unterminated trace length before transmission-line effects dominate: ℓmax ≈ tr · vp/6, where tr is signal rise time and vp is propagation velocity (≈ 1.5 × 10⁸ m/s in FR4 microstrip). For a 170 MHz MCU with GPIO rise times on the order of 2–3 ns, ℓmax ≈ (2.5ns × 1.5 × 10⁸
)/6 ≈ 62 mm – comfortably longer than any on-board SPI run, so series termination is not strictly required but a 22–33 Ω series resistor at the driver is recommended as cheap insurance against ringing on the fastest (SPI to RTC6705) link.
- Maintain minimum 3× trace-width spacing (“3W rule”) between adjacent parallel digital traces to limit crosstalk, increasing to 5W for the CVBS analog trace relative to any digital neighbor.
- Layer transitions (vias) on signal nets that change reference plane (e.g., L1 GND-referenced to L4 GND-referenced) do not by themselves introduce meaningful reflections at these edge rates; however, a stitching via connecting the two reference planes shall be placed within ∼1.5 mm of every such signal via to give the return current a short, low-inductance path – omitting the stitching via (not the signal via itself) is the actual common root cause of degraded signal quality at layer transitions.
- Right-angle (90◦
) corners are acceptable for all digital traces in this design at these edge rates and do not measurably increase EMI at these frequencies; 45◦
chamfers are used by convention for manufacturability/etch consistency rather than as an SI requirement.

### 8.3 RF Trace Design (5.8 GHz, RTC6659E to U.FL)

The PA-to-antenna trace shall be implemented as a 50 Ω Coplanar Waveguide with Ground (CPWG), referenced to the L2 ground plane below and flanked by a stitched coplanar ground pour on L1.

Design Note — Illustrative CPWG Solution (verify with 2D field solver): For the L1-to-L2 dielectric height of h = 0.10 mm and εr ≈ 4.2 specified in Table 13, a representative solver-derived

8.4 Vias, Corners, and Stubs – Consolidated Rules | 9 RF SUBSYSTEM DESIGN (VTX)

solution achieving ≈ 50 Ω±5% is: trace width W ≈ 0.22–0.25 mm, coplanar gap G ≈ 0.13–0.16 mm to the adjacent ground pour, 1 oz copper. These values are illustrative only and shall be confirmed with a 2D field solver (e.g., Polar SI9000, Saturn PCB Toolkit, or the fabricator’s stackup calculator) against the as-built dielectric thickness and resin content before tape-out, per REQ-SI-002 below.

### 8.3.1 Ground Stitching Via Fence

To suppress parallel-plate/coplanar mode leakage and maintain waveguide behavior, a via fence of grounded stitching vias shall flank the CPWG trace on both sides. Guided wavelength at 5.8 GHz for εr,ef f ≈ 3.0 (typical effective permittivity for a CPWG on FR4-class material, accounting for field lines partly in air):

λg =

c
f

√εr,ef f

=

3 × 10⁸

5.8 × 10⁹ ×

√
3.0

≈ 29.9 mm

Applying the standard λg/10 to λg/20 via-spacing guideline yields a maximum stitching via pitch of 1.5–3.0 mm; this design specifies ≤2.0 mm pitch for margin, with via-to-trace-edge spacing kept as small as the design rules allow (≥0.2 mm clearance to the coplanar ground pour edge).

### 8.4 Vias, Corners, and Stubs – Consolidated Rules

Feature | Rule
Signal vias (digi- tal) | Permitted freely; pair with a ground stitching via for reference-
| plane continuity (Section 8, digital rules).
Signal vias (RF, 5.8 GHz) | Minimize; if unavoidable (e.g., L1-to-L3 transition), use back-
| drilling or a blind via to remove the unused stub capacitance,
| and surround with a ground via fence at ≤2 mm pitch.
Right-angle bends (digital) | Acceptable; no measurable SI or EMI penalty at these edge
| rates.
Right-angle bends (RF) | Not acceptable – use smooth arcs or 45◦/mitered bends for the
| 5.8 GHz CPWG; sharp corners create a local impedance discon-
| tinuity and radiating discontinuity that is significant relative to
| the guided wavelength at microwave frequencies.
Stubs (all nets) | Prohibited. Any unused via stub, test point spur, or dangling
| net segment on a controlled-impedance or RF net shall be re-
| moved or back-drilled.

### 8.5 Signal Integrity Verification Requirements

- REQ-SI-001: All controlled-impedance nets shall be called out on the fab drawing with target impedance and tolerance per Table 13/impedance targets table.
- REQ-SI-002: RF trace geometry shall be confirmed by field-solver simulation prior to layout freeze, and by TDR measurement on a fabricated coupon before production release.
- REQ-SI-003: A minimum of one ground stitching via per 1.5 mm shall be placed adjacent to every signal via that changes ground reference plane on SPI/UART nets.

### 9 RF Subsystem Design (VTx)

### 9.1 RTC6705 Configuration

The RTC6705 integrates the PLL frequency synthesizer and FM video modulator. The MCU configures the output frequency and power level over a 3-wire SPI-like interface by writing to internal

9.2 Standard 5.8 GHz Band Plan | 9 RF SUBSYSTEM DESIGN (VTX)

25-bit registers (frequency synthesis register N/A/R divider values per the RTC6705 datasheet register map). Firmware shall abstract this behind a simple vtx_set_channel(band, channel) / vtx_set_power(level) API, with the resolved register values validated in unit test against the vendor reference table.

### 9.2 Standard 5.8 GHz Band Plan

The firmware shall support, at minimum, the following industry-standard band plan (channel numbering and frequencies consistent with common FPV goggle/VRx convention):

Band | CH1 | CH2 | CH3 | CH4 | CH5 | CH6 | CH7 | CH8
A (Boscam A) | 5865 | 5845 | 5825 | 5805 | 5785 | 5765 | 5745 | 5725
B (Boscam B) | 5733 | 5752 | 5771 | 5790 | 5809 | 5828 | 5847 | 5866
E (Boscam E / DJI) | 5705 | 5685 | 5665 | 5645 | 5885 | 5905 | 5925 | 5945
F (Fatshark / IRC) | 5740 | 5760 | 5780 | 5800 | 5820 | 5840 | 5860 | 5880
R (Raceband) | 5658 | 5695 | 5732 | 5769 | 5806 | 5843 | 5880 | 5917

Table 16: 5.8 GHz analog FPV band plan, frequencies in MHz. All 40 channels shall be exposed in firmware; region-locked builds shall mask out-of-band channels per REQ-EMC-003 at compile time or via a region-configuration record in non-volatile storage, not left to the end user to self-police.

△ Caution — Regulatory Scope: Bands outside the 5.725–5.875 GHz ISM allocation for a given region (e.g., portions of Band E) may fall outside the legal FCC/ETSI allocation depending on jurisdiction. Firmware region-lock tables shall be maintained and reviewed against current regulatory publications at each firmware release; this document does not substitute for a regulatory compliance sign-off.

### 9.3 Power Level Control

Three discrete power levels shall be supported, mapped to RTC6659E PA bias/gain control:

Level | Nom. Power | Typ. Use Case | Regulatory Fit
Low | 25 mW | Default/boot | state, | close-
range bench test

EU/ETSI EN 300 440 compliant

Medium | 200 mW | Regional (e.g., select non-EU
jurisdictions)

Verify local allocation before use

High | 400 mW | Long-range observation mis-
| sions

US FCC Part 15.247 typical allowance (verify EIRP with antenna gain)

Table 17: VTx power levels. Firmware shall boot to Low by default (REQ-EMC-003) and require an explicit, logged configuration change to enable Medium/High.

### 9.4 Thermal Management of the PA

The RTC6659E dissipates the difference between DC input power and RF output power as heat (efficiency on the order of 30–40% typical for this PA class at 400 mW output, implying ∼0.6–0.9W dissipated as heat at full power). A thermal via array (≥9 vias, 0.3 mm drill, on 1.0 mm pitch) beneath the PA’s exposed thermal pad shall connect to an internal copper pour on L3/L5 to spread heat, and firmware shall implement the PA thermal throttle per REQ-SAF-003.

11 DFM / MECHANICAL RELIABILITY

### 10 EMI/EMC & Shielding Strategy

### 10.1 Physical Partitioning

- The RTC6705/RTC6659E RF island shall be located at the board edge nearest the antenna connector, and separated from the BMI270 IMU and the compass by a minimum of 25 mm or by an intervening ground-via “moat,” whichever provides greater practical isolation.
- The compass (QMC5883L) shall additionally be kept clear of high-current DC paths (buck inductor, servo header, battery input traces) by a minimum of 15 mm, since DC bias fields from switching currents directly corrupt magnetometer readings, independent of RF concerns.
- The analog CVBS trace shall be routed away from the RF island and from the buck converter’s switching node, both of which are broadband noise sources capable of coupling into the unshielded composite video signal and appearing as visible interference (“rainbow noise”) in the downlink image.

### 10.2 RF Shielding Can

A grounded, tin-plated (or nickel-silver) RF shielding can footprint shall be provided over the RTC6705 + RTC6659E + matching network area, soldered to a continuous ground-via fence around its perimeter (pitch ≤2 mm, consistent with Section 8) to present a low-impedance return path for the can itself. The can shall include a cutout or feedthrough for the CPWG trace to the antenna connector, with the gap treated as a slot antenna risk and minimized (<0.5 mm clearance beyond the trace/coplanar ground).

### 10.3 Conducted/Coupled Noise Mitigation

- Ferrite bead + local decoupling “pi filter” on the PA’s 5 V feed (Section 6) to block PA envelopekeying noise from the shared 5 V domain.
- Common-mode choke on the UART lines to the camera module and GPS module where cable runs exceed ∼50 mm, to suppress common-mode RF pickup on these longer runs.
- Ground stitching vias (population ≥1 per 100 mm²
) across the full board to minimize groundplane impedance and suppress ground-bounce coupling between the digital and RF/analog domains.

### 10.4 Pre-Compliance Test Plan

- Near-field H-field/E-field probe scan across the board with a spectrum analyzer to identify unintended radiators prior to formal compliance testing.
- Conducted emissions on the battery input leads (relevant if this FC is later integrated with a shared power bus alongside other RF-sensitive payloads).
- IMU/compass noise-floor comparison with VTx PA keyed on vs. off (REQ-EMC-002 verification).
- Full FCC Part 15.247 / ETSI EN 300 440 formal compliance testing at an accredited lab prior to any commercial release (out of scope for internal pre-compliance testing described here).

### 11 DFM / Mechanical Reliability

### 11.1 Mounting & Vibration Isolation

The board shall use the industry-standard 30.5 mm × 30.5 mm FC mounting pattern with 4 mm diameter mounting holes to accept silicone/rubber vibration-damping grommets. Grommet durometer shall be selected (typically 55A–65A Shore hardness) to filter motor/propeller-induced vibration frequencies (typically 80–400 Hz fundamental for the target propeller sizes) from reaching the BMI270

11.2 Board Outline & Connector Keepouts 12 FIRMWARE & CONTROL ARCHITECTURE

IMU, consistent with REQ-ENV-002. Grommet compression at installation shall be specified at 10– 15% of free height to maintain consistent damping without bottoming out under sustained 1 g load plus vibration.

### 11.2 Board Outline & Connector Keepouts

- Maintain a minimum 3 mm keepout from board edge to any component taller than 2 mm, to accommodate a protective frame/standoff without interference.
- U.FL antenna connector placed at the board edge with the RF trace as short and direct as practical (Section 8).
- Power input (XT30/XT60 pigtail or bullet-connector footprint) shall be routed with ≥1.5 mm trace width per ounce of copper per amp of continuous current (approx. 20 mil/A at 1 oz copper, 10◦C rise) for the 2.8 A transient budget – i.e., a minimum 2.0 mm (80 mil) power trace width on 2 oz copper for the main input, or equivalent via-stitched multi-layer pour.

### 11.3 Fabrication & Assembly Class

- Fabrication per IPC-6012 Class 2 (general electronics) as the baseline; Class 3 workmanship notes applied specifically to the RF island solder joints and the servo/power connectors, which see the highest mechanical and thermal cyclic stress.
- Assembly (solder joint) acceptance per IPC-A-610 Class 2.
- Minimum annular ring, minimum drill size, and minimum trace/space shall be confirmed against the selected fabricator’s standard capability table at DFM review, with ≥4 mil/4 mil (0.1 mm/0.1 mm) trace/space assumed as the baseline design rule for this stackup.

### 11.4 Conformal Coating

Per REQ-ENV-003, a conformal coating (acrylic or silicone-based, selected for rework compatibility) shall be applied post-assembly, with the U.FL connector, SD card slot, and any user-adjustable connectors masked prior to coating. Coating shall not be applied over the RF shielding can’s ground contact fingers if a spring-finger can is used, to preserve electrical continuity.

### 11.5 Connector Selection

Interface | Connector | Notes
Battery input | XT30 (pigtail) or solder pads | Rated ≥30 A continuous; oversized for this load, standard for the platform class
Camera video/control | JST-SH 1.0 mm, 4-pin | Matches RunCam Split 4 V3 factory pigtail
Servo | JST-SH 1.0 mm, 3-pin (or bare pads) | GND/5 V/PWM per Section 1
Antenna | U.FL (or MMCX for field durability) | U.FL has limited mating cycle life (∼30); MMCX recommended if frequent antenna swaps expected in the field

Table 18: Connector selection summary.

### 12 Firmware & Control Architecture

### 12.1 Task Scheduling

A bare-metal, interrupt-driven scheduler (rather than a full RTOS) is recommended given the bounded, well-characterized task set, consistent with common flight-controller firmware architecture:

11.2 Board Outline & Connector Keepouts 12 FIRMWARE & CONTROL ARCHITECTURE

Task | Rate | Priority
IMU sampling (BMI270, SPI DMA) | 6.4–8 kHz | Highest (hardware timer + DMA
complete IRQ)
Attitude/rate control loop | 2–4 kHz | High
Barometer fusion | 50 Hz | Medium
GPS parse (UART3 + PPS capture) | 10 Hz (nav), async PPS | Medium
Servo | PWM | update | (double-
buffered)
50 Hz | Low

Camera UART housekeeping / telemetry

10 Hz poll, event-driven commands

Low

VTx SPI configuration | Event-driven (channel/power
change only)

Low

Battery/thermal monitoring (ADC) | 10 Hz | Medium (safety-relevant)

Table 19: Firmware task rates. The control loop (2–4 kHz) exceeds REQ-PERF-002’s 2 kHz minimum with margin for future gain-scheduling or notch-filter additions.

### 12.2 Camera Control Protocol

The UART link to the RunCam Split 4 V3 shall implement the RunCam Device Protocol (or equivalent vendor-published serial protocol) to: (a) start/stop SD recording, (b) query recording/SD status for OSD display, and (c) optionally forward OSD text elements for overlay on the CVBS output. A 3-retry/200 ms-timeout handshake (Section 4.3) governs link-health detection.

### 12.3 Fault Handling & Watchdogs

- Independent hardware watchdog (IWDG) on the STM32, refreshed only from the main control loop context, to force a reset on control-loop lockup.
- Brown-out reset (BOR) threshold configured above the minimum operating voltage of the 3.3 VDIG rail with margin, to guarantee clean reset behavior rather than erratic operation during a sagging bus.
- VTx channel/power configuration persisted to internal flash (or EEPROM emulation) so a power cycle resumes on the last configured channel without requiring re-pairing with the ground receiver.
- GPS fix loss: position-hold mode shall gracefully degrade to altitude-hold-only (barometer) with a telemetry warning, rather than an uncommanded mode fault.

### 13 Verification & Validation Plan

Req. ID | Test Method | Acceptance Criteria
REQ-CAM- 001/002 | Bench recording test, 30- min continuous 4K@30 + simultaneous CVBS cap- ture | No dropped frames (verified via frame- hash continuity check); CVBS sig- nal within CCIR/EIA timing spec on waveform monitor
REQ-GIM- 001/002 | Bench servo sweep + RC failsafe injection | Full 120◦ mechanical travel confirmed;
| | failsafe-to-safe-position time ≤500 ms measured via oscilloscope on PWM line and optical encoder on servo horn
REQ-VTX- 001/002 | SPI register readback + spectrum analyzer chan- nel/power verification | Measured frequency within ±1 MHz of Table 16; measured EIRP within ±1 dB of configured level

11.2 Board Outline & Connector Keepouts 12 FIRMWARE & CONTROL ARCHITECTURE

Req. ID | Test Method | Acceptance Criteria

REQ-PERF-

001 | Glass-to-glass latency test (high-speed camera com- paring live scene to goggle display) | ≤80 ms measured

REQ-PERF-002

IMU/loop-rate logging via
debug UART

Confirmed ≥6.4 kHz IMU, ≥2 kHz control loop in flight log
REQ-PERF-003

Range test, line-of-sight, calibrated attenuator bench pre-test then field range test

≥2 km achieved with ≥6 dB link margin

REQ-ENV-002

MIL-STD-810H Method
514.8 random vibration,
3-axis

No solder joint failure (5× magnification inspection), no component detachment, IMU output noise floor within spec post-test
REQ-EMC-002

IMU/GPS/baro noise floor,
PA keyed vs. unkeyed

≤1 dB (or 1 LSB-equivalent) degradation
VER-PWR-03

Simulated power-loss during active SD write (bench PSU step to 0 V)

File system closes cleanly, no corrupted video container, confirmed across 20 repeated trials
VER-PWR-04
Thermal | imaging | of
buck/PA under sustained
max load, 45◦C chamber,
no airflow

Junction/case temperatures within datasheet limits with ≥15◦C margin

REQ-SI-002 TDR measurement on fabricated coupon

CPWG | impedance | 50 Ω ± 5%;
SPI/UART microstrip 50 Ω ± 10%

Table 20: Verification cross-reference matrix (representative subset; full matrix maintained in the program’s requirements-management tool).

### 14 Risk Register / FMEA (Summary)

Component/
Function
Failure Mode | Effect | Sev. | Mitigation
RTC6659E PA | Thermal runaway un-
der sustained 400 mW | Video downlink loss, potential PA damage | High | Thermal via array + firmware ther-
mal | throttle
| | | (REQ-SAF- 003)
Servo | Mechanical stall /
winding burnout | Loss of camera aim, potential rail brown- out | Med | Current mon-
itoring | +
| | | auto-neutral (Section 4.3)
SD card | Card failure / write
corruption mid-flight
Loss | of | recorded
footage | (non-flight-
| critical)
Med | Bulk | capaci-
| | | tance hold-up (Section 6.6); status teleme- try to pilot

11.2 Board Outline & Connector Keepouts 12 FIRMWARE & CONTROL ARCHITECTURE

Component/
Function
Failure Mode | Effect | Sev. | Mitigation
Compass | Magnetic interference
from nearby current loops | Heading drift, navi- gation error
High | Physical | sep-
aration | rules
(Section | 10);
| | | in-flight com-
pass | health
| | | monitor com-
paring | GPS
course | vs.
| | | heading
Buck converter | Output | overvoltage
(component | failure,
latch-up) | Overvoltage to 5 V loads, potential cam- era/servo damage | High | Consider
adding | an
output | crow-
| | | bar/OVP
clamp | –
tracked | as
| | | OPEN-04
VTx | region-
lock table

Firmware misconfiguration ships with
wrong region default
Regulatory | non-
| compliance | High | Release build
process | shall
assert | region
| | | default at com- pile time with
a | mandatory
| | | build-config check

Table 21: Summary risk register. Full FMEA with occurrence/detection scoring (RPN) maintained in the program risk-tracking system.

### 15 Open Items / Action Log

ID | Description | Owner

OPEN-

01 | Confirm airframe housing provides ≥3 mm ventilation clearance around the camera processing board to avoid sustained-recording thermal throttling. | Mech. Eng.

OPEN-

02 | Select and validate the digital 3.3 V LDO part (placeholder TLV75533) against noise/PSRR requirements for the MCU/IMU rail. | Elec. Eng.

OPEN-

03 | Evaluate second-source RF chipset (e.g., IRC Tramp-compatible) against RTC6705/RTC6659E for supply-chain risk mitigation. | Procurement
/ | RF
| | Eng.
OPEN-
04 | Evaluate adding output overvoltage protection (crowbar or clamp) on the 5 V rail per FMEA risk item. | Elec. Eng.

OPEN-

05 | Confirm final regulatory target markets to lock the de- fault/maximum VTx power level and region-lock table contents (originally raised as: which 5.8 GHz bands – FatShark, Raceband, etc. – must firmware support?). | Program Mgmt.

OPEN-06

Confirm connector choice (U.FL vs. MMCX) based on expected field antenna-swap frequency.

Mech.
Eng.

12.1 Task Scheduling | 12 FIRMWARE & CONTROL ARCHITECTURE
ID | Description | Owner

Table 22: Open items requiring resolution before Critical Design Review (CDR).

B APPENDIX B: REFERENCES

### A Appendix A: STM32G473CEU6 Pin/Peripheral Mapping (Preliminary)

Pin | Function | Peripheral | Net
PA5/PA6/PA7 | SPI1 SCK/MISO/MOSI | SPI1 | IMU_SCK/MISO/MOSI
PA4 | SPI1 CS | GPIO | IMU_CS
PB13/PB14/PB15 | SPI2 SCK/MISO/MOSI | SPI2 | VTX_SCK/MISO/MOSI
PB12 | SPI2 CS | GPIO | VTX_CS
PB6/PB7 | I2C1 SCL/SDA | I2C1 | BARO/COMPASS bus
PC10/PC11 | UART3 TX/RX | USART3 | GPS TX/RX
PB10/PB11 | UART3 alt. or UART4 | USART | Camera control UART
PA0 (TIM2_CH1) | Servo PWM | TIM2 | GIMBAL_PWM
PA1 | PPS capture input | TIM input capture | GPS_PPS
PC0 (ADC1_IN6) | Battery voltage sense | ADC1 | VBAT_SENSE
PC1 (ADC1_IN7) | Servo current sense | ADC1 | SERVO_ISENSE

Table 23: Preliminary pin mapping. Final assignment subject to PCB layout/routing optimization; this table shall be kept in sync with the schematic net list at each revision.

### B Appendix B: References

1. IPC-2221, IPC-2141A, IPC-6012, IPC-A-610 (IPC International, Inc.)
2. STM32G473xx Datasheet and Reference Manual (RM0440), STMicroelectronics
3. BMI270 Datasheet, Bosch Sensortec
4. DPS310 Datasheet, Infineon Technologies
5. MAX-M10S Integration Manual, u-blox
6. RTC6705 / RTC6659E Datasheets, RichWave Technology
7. TPS54302 / TPS7A8300 Datasheets, Texas Instruments
8. FCC Part 15, Subpart C; ETSI EN 300 440 (regulatory text, respective publishing bodies)
9. MIL-STD-810H, Method 514.8 (Vibration), U.S. Department of Defense
10. Bogatin, E., Signal and Power Integrity – Simplified, for general PDN target-impedance and via/right-angle-bend engineering guidance referenced qualitatively in Section 8.

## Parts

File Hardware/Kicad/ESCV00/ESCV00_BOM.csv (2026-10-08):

Qty | References | Value | Footprint | Manufacturer | MPN | Populate
24 | C1 C2 C4 C7 C101 C102 C105 C106 C108 C201 C202 C205 C206 C208 C301 C302 C305 C306 C308 C401 C402 C405 C406 C408 | 100nF | C_0402_1005Metric |  |  | yes
1 | C3 | 10nF | C_0402_1005Metric |  |  | yes
1 | C5 | 2.2uF 50V | C_0805_2012Metric |  |  | yes
5 | C6 C114 C214 C314 C414 | 100nF 50V | C_0603_1608Metric |  |  | yes
6 | C8 C9 C107 C207 C307 C407 | 10uF 25V | C_0805_2012Metric |  |  | yes
1 | C10 | 1uF 25V | C_0603_1608Metric |  |  | yes
1 | C11 | 4.7uF 10V | C_0603_1608Metric |  |  | yes
8 | C103 C104 C203 C204 C303 C304 C403 C404 | 1uF | C_0402_1005Metric |  |  | yes
12 | C109 C110 C111 C209 C210 C211 C309 C310 C311 C409 C410 C411 | 1uF 25V X7R | C_0603_1608Metric |  |  | yes
8 | C112 C113 C212 C213 C312 C313 C412 C413 | 10uF 50V X7R | C_1206_3216Metric |  |  | yes
1 | D1 | PMEG6010CEH | D_SOD-123F |  | PMEG6010CEH,115 | yes
1 | D2 | GREEN | LED_0603_1608Metric |  |  | yes
4 | FB101 FB201 FB301 FB401 | 120R@100MHz | L_0402_1005Metric |  | BLM15PX121SN1D | yes
1 | J1 | FC | JST_SH_SM08B-SRSS-TB_1x08-1MP_P1.00mm_Horizontal | JST | SM08B-SRSS-TB(LF)(SN) | yes
1 | L1 | 10uH SWPA3012S-100MT | L_Sunlord_SWPA3012S | Sunlord | SWPA3012S100MT | yes
24 | Q101 Q102 Q103 Q104 Q105 Q106 Q201 Q202 Q203 Q204 Q205 Q206 Q301 Q302 Q303 Q304 Q305 Q306 Q401 Q402 Q403 Q404 Q405 Q406 | BSZ018N04LS6 | PQFN-8_3.3x3.3mm_P0.65mm_PowerFET | Infineon | BSZ018N04LS6ATMA1 | yes
4 | R1 R2 R3 R4 | 1mR 3W | R_2512_6332Metric | Vishay | WSLP2512R0010FEA | yes
2 | R5 R6 | 10R | R_0402_1005Metric |  |  | yes
6 | R7 R13 R103 R203 R303 R403 | 1k | R_0402_1005Metric |  |  | yes
2 | R8 R12 | 10k 1% | R_0402_1005Metric |  |  | yes
1 | R9 | 1k 1% | R_0402_1005Metric |  |  | yes
1 | R10 | 100k | R_0402_1005Metric |  |  | yes
1 | R11 | 121k 1% | R_0402_1005Metric |  |  | yes
5 | R14 R101 R201 R301 R401 | 10k | R_0402_1005Metric |  |  | yes
4 | R102 R202 R302 R402 | 100R | R_0402_1005Metric |  |  | yes
24 | R104 R105 R109 R110 R114 R115 R204 R205 R209 R210 R214 R215 R304 R305 R309 R310 R314 R315 R404 R405 R409 R410 R414 R415 | 4.7R | R_0402_1005Metric |  |  | yes
24 | R106 R108 R111 R113 R116 R118 R206 R208 R211 R213 R216 R218 R306 R308 R311 R313 R316 R318 R406 R408 R411 R413 R416 R418 | 20k | R_0402_1005Metric |  |  | yes
12 | R107 R112 R117 R207 R212 R217 R307 R312 R317 R407 R412 R417 | 2.2k | R_0402_1005Metric |  |  | yes
4 | R119 R219 R319 R419 | 750R | R_0402_1005Metric |  |  | yes
1 | TP1 | BAT+ | SolderPad_5x8mm |  |  | yes
1 | TP2 | BAT- | SolderPad_5x8mm |  |  | yes
1 | TP3 | +3V3 | TestPoint_Pad_D1.5mm |  |  | yes
1 | TP4 | GND | TestPoint_Pad_D1.5mm |  |  | yes
1 | TP5 | +10V | TestPoint_Pad_D1.5mm |  |  | yes
1 | TP6 | M1A | SolderPad_3x5mm |  |  | yes
1 | TP7 | M1B | SolderPad_3x5mm |  |  | yes
1 | TP8 | M1C | SolderPad_3x5mm |  |  | yes
1 | TP9 | M2A | SolderPad_3x5mm |  |  | yes
1 | TP10 | M2B | SolderPad_3x5mm |  |  | yes
1 | TP11 | M2C | SolderPad_3x5mm |  |  | yes
1 | TP12 | M3A | SolderPad_3x5mm |  |  | yes
1 | TP13 | M3B | SolderPad_3x5mm |  |  | yes
1 | TP14 | M3C | SolderPad_3x5mm |  |  | yes
1 | TP15 | M4A | SolderPad_3x5mm |  |  | yes
1 | TP16 | M4B | SolderPad_3x5mm |  |  | yes
1 | TP17 | M4C | SolderPad_3x5mm |  |  | yes
4 | TP101 TP201 TP301 TP401 | SWDIO | TestPoint_Pad_D1.0mm |  |  | yes
4 | TP102 TP202 TP302 TP402 | SWCLK | TestPoint_Pad_D1.0mm |  |  | yes
4 | TP103 TP203 TP303 TP403 | NRST | TestPoint_Pad_D1.0mm |  |  | yes
1 | U1 | INA181A3IDBVR | SOT-23-6 | Texas Instruments | INA181A3IDBVR | yes
1 | U2 | LMR16006YDDCR | SOT-23-6 | Texas Instruments | LMR16006YDDCR | yes
1 | U3 | MCP1703AT-3302E_MB | SOT-89-3 | Microchip | MCP1703AT-3302E/MB | yes
4 | U101 U201 U301 U401 | STM32F051K8U6 | QFN-32-1EP_5x5mm_P0.5mm_EP3.45x3.45mm | STMicroelectronics | STM32F051K8U6 | yes
4 | U102 U202 U302 U402 | DRV8300DRGER | VQFN-24-1EP_4x4mm_P0.5mm_EP2.45x2.45mm | Texas Instruments | DRV8300DRGER | yes

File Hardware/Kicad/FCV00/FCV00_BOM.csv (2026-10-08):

Qty | References | Value | Footprint | Manufacturer | MPN | Populate
2 | C1 C2 | 10uF 50V X7R | C_1206_3216Metric |  |  | yes
5 | C3 C6 C9 C14 C17 | 100nF 50V | C_0603_1608Metric |  |  | yes
22 | C4 C12 C20 C23 C26 C27 C28 C29 C30 C31 C34 C39 C41 C43 C44 C45 C47 C48 C49 C50 C53 C54 | 100nF | C_0402_1005Metric |  |  | yes
2 | C5 C13 | 2.2uF 50V | C_0805_2012Metric |  |  | yes
1 | C7 | 6.8nF | C_0402_1005Metric |  |  | yes
1 | C8 | 47pF | C_0402_1005Metric |  |  | yes
2 | C10 C11 | 22uF 16V X5R | C_0805_2012Metric |  |  | yes
1 | C15 | 4.7nF | C_0402_1005Metric |  |  | yes
1 | C16 | 33pF | C_0402_1005Metric |  |  | yes
2 | C18 C19 | 22uF 25V X5R | C_1206_3216Metric |  |  | yes
3 | C21 C24 C40 | 1uF 16V | C_0402_1005Metric |  |  | yes
3 | C22 C25 C32 | 4.7uF 10V | C_0603_1608Metric |  |  | yes
2 | C33 C42 | 1uF | C_0402_1005Metric |  |  | yes
2 | C35 C36 | 2.2uF | C_0402_1005Metric |  |  | yes
4 | C37 C38 C51 C52 | 18pF NP0 | C_0402_1005Metric |  |  | yes
1 | C46 | 10uF 10V | C_0603_1608Metric |  |  | yes
1 | C55 | 10uF 25V | C_0805_2012Metric |  |  | yes
1 | D1 | SMAJ28A | D_SMA |  | SMAJ28A | yes
2 | D2 D3 | PMEG6045ETP | D_SOD-128 |  | PMEG6045ETPX | yes
1 | D4 | PMEG3020EH | D_SOD-123F |  | PMEG3020EH,115 | yes
1 | D5 | RED | LED_0603_1608Metric |  | KT-0603R | yes
1 | D6 | BLUE | LED_0603_1608Metric |  |  | yes
1 | D7 | GREEN | LED_0603_1608Metric |  |  | yes
1 | D8 | USBLC6-2SC6 | SOT-23-6 | STMicroelectronics | USBLC6-2SC6 | yes
1 | D9 | 1N4148W | D_SOD-123 |  | 1N4148W | yes
1 | FB1 | 600R@100MHz | L_0402_1005Metric |  | BLM15AG601SN1D | yes
1 | FB2 | 600R@100MHz | L_0603_1608Metric |  | BLM18AG601SN1D | yes
1 | J1 | USB_C_GCT_USB4105-GF-A | USB_C_Receptacle_GCT_USB4105-xx-A_16P_TopMnt_Horizontal | GCT | USB4105-GF-A | yes
1 | J2 | ESC | JST_SH_SM08B-SRSS-TB_1x08-1MP_P1.00mm_Horizontal | JST | SM08B-SRSS-TB(LF)(SN) | yes
1 | J3 | RX | JST_SH_SM04B-SRSS-TB_1x04-1MP_P1.00mm_Horizontal | JST | SM04B-SRSS-TB(LF)(SN) | yes
1 | J4 | VTX | JST_SH_SM06B-SRSS-TB_1x06-1MP_P1.00mm_Horizontal | JST | SM06B-SRSS-TB(LF)(SN) | yes
1 | J5 | CAM | JST_SH_SM03B-SRSS-TB_1x03-1MP_P1.00mm_Horizontal | JST | SM03B-SRSS-TB(LF)(SN) | yes
1 | J6 | GPS | JST_SH_SM06B-SRSS-TB_1x06-1MP_P1.00mm_Horizontal | JST | SM06B-SRSS-TB(LF)(SN) | yes
1 | J7 | AUX | JST_SH_SM06B-SRSS-TB_1x06-1MP_P1.00mm_Horizontal | JST | SM06B-SRSS-TB(LF)(SN) | yes
1 | JP1 | CAM 5V|10V | SolderJumper-3_P1.3mm_Open_RoundedPad1.0x1.5mm |  |  | yes
1 | L1 | 6.8uH SRP5030T-6R8M | L_Bourns_SRP5030T | Bourns | SRP5030T-6R8M | yes
1 | L2 | 10uH SRP5030T-100M | L_Bourns_SRP5030T | Bourns | SRP5030T-100M | yes
1 | Q1 | 2N7002 | SOT-23 | Nexperia | 2N7002,215 | yes
2 | R1 R12 | 10k 1% | R_0402_1005Metric |  |  | yes
1 | R2 | 1k 1% | R_0402_1005Metric |  |  | yes
1 | R3 | 470k | R_0402_1005Metric |  |  | yes
2 | R4 R34 | 100k | R_0402_1005Metric |  |  | yes
2 | R5 R9 | 121k 1% | R_0402_1005Metric |  |  | yes
1 | R6 | 16.9k | R_0402_1005Metric |  |  | yes
1 | R7 | 53.6k 1% | R_0402_1005Metric |  |  | yes
1 | R8 | 10.2k 1% | R_0402_1005Metric |  |  | yes
1 | R10 | 24.9k | R_0402_1005Metric |  |  | yes
1 | R11 | 115k 1% | R_0402_1005Metric |  |  | yes
5 | R13 R16 R17 R31 R33 | 1k | R_0402_1005Metric |  |  | yes
8 | R14 R15 R20 R22 R25 R26 R27 R28 | 10k | R_0402_1005Metric |  |  | yes
2 | R18 R19 | 5.1k | R_0402_1005Metric |  |  | yes
1 | R21 | 20k | R_0402_1005Metric |  |  | yes
2 | R23 R24 | 2.2k | R_0402_1005Metric |  |  | yes
1 | R29 | 75R 1% | R_0402_1005Metric |  |  | yes
1 | R32 | 33R | R_0402_1005Metric |  |  | yes
1 | SW1 | BOOT | SW_SPST_B3U-1000P | Omron | B3U-1000P | yes
1 | TP1 | BAT+ | SolderPad_3x5mm |  |  | yes
1 | TP2 | BAT- | SolderPad_3x5mm |  |  | yes
1 | TP3 | SWDIO | TestPoint_Pad_D1.0mm |  |  | yes
1 | TP4 | SWCLK | TestPoint_Pad_D1.0mm |  |  | yes
1 | TP5 | NRST | TestPoint_Pad_D1.0mm |  |  | yes
1 | TP6 | +3V3 | TestPoint_Pad_D1.0mm |  |  | yes
1 | TP7 | GND | TestPoint_Pad_D1.0mm |  |  | yes
1 | TP8 | LED | TestPoint_Pad_2.0x2.0mm |  |  | yes
1 | TP9 | 5V | TestPoint_Pad_2.0x2.0mm |  |  | yes
1 | TP10 | GND | TestPoint_Pad_2.0x2.0mm |  |  | yes
1 | TP11 | BZ+ | TestPoint_Pad_2.0x2.0mm |  |  | yes
1 | TP12 | BZ- | TestPoint_Pad_2.0x2.0mm |  |  | yes
2 | U1 U2 | TPS54360BDDAR | TI_SO-PowerPAD-8_ThermalVias | Texas Instruments | TPS54360BDDAR | yes
2 | U3 U4 | AP2112K-3.3TRG1 | SOT-23-5 | Diodes Inc | AP2112K-3.3TRG1 | yes
1 | U5 | STM32F405RGT6 | LQFP-64_10x10mm_P0.5mm | STMicroelectronics | STM32F405RGT6 | yes
1 | U6 | ICM-42688-P | Bosch_LGA-14_3x2.5mm_P0.5mm | TDK InvenSense | ICM-42688-P | yes
1 | U7 | LPS22DF | ST_HLGA-10_2x2mm_P0.5mm_LayoutBorder3x2y | STMicroelectronics | LPS22DFTR | yes
1 | U8 | W25Q128JVSIQ | SOIC-8_5.23x5.23mm_P1.27mm | Winbond | W25Q128JVSIQ | yes
1 | U9 | AT7456E | HTSSOP-28-1EP_4.4x9.7mm_P0.65mm_EP2.85x5.4mm | Shenzhen Zhongkewei (ZKW) | AT7456E | yes
1 | Y1 | 8MHz 12pF | Crystal_SMD_3225-4Pin_3.2x2.5mm | Yangxing | X322508MLB4SI | yes
1 | Y2 | 27MHz 12pF | Crystal_SMD_3225-4Pin_3.2x2.5mm | Yangxing | X322527MOB4SI | yes
1 | R30 | 0R | R_0402_1005Metric |  |  | DNP

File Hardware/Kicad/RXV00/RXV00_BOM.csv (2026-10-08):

Qty | References | Value | Footprint | Manufacturer | MPN | Populate
1 | AE1 | 2450AT18A100 | Johanson_2450AT18x100 | Johanson | 2450AT18A100E | yes
1 | C1 | 4.7uF 10V | C_0603_1608Metric |  |  | yes
2 | C2 C15 | 10uF 10V | C_0603_1608Metric |  |  | yes
7 | C3 C4 C5 C6 C7 C16 C17 | 100nF | C_0402_1005Metric |  |  | yes
3 | C8 C9 C10 | 1uF | C_0402_1005Metric |  |  | yes
2 | C11 C12 | 12pF NP0 | C_0402_1005Metric |  |  | yes
2 | C18 C20 | 470nF | C_0402_1005Metric |  |  | yes
1 | C19 | 47pF NP0 | C_0402_1005Metric |  |  | yes
1 | C21 | 10pF NP0 | C_0402_1005Metric |  |  | yes
2 | C22 C23 | 1pF NP0 | C_0402_1005Metric |  |  | yes
1 | D1 | BLUE | LED_0603_1608Metric |  |  | yes
1 | FB1 | 120R@100MHz | L_0402_1005Metric |  | BLM15PX121SN1D | yes
1 | J1 | FC | JST_SH_SM04B-SRSS-TB_1x04-1MP_P1.00mm_Horizontal | JST | SM04B-SRSS-TB(LF)(SN) | yes
1 | J2 | U.FL | U.FL_Hirose_U.FL-R-SMT-1_Vertical | Hirose | U.FL-R-SMT-1(10) | yes
1 | L1 | 0R / tune | L_0402_1005Metric |  |  | yes
1 | L2 | 15uH | L_0805_2012Metric | Murata | LQM21PN150MC0 | yes
1 | L3 | 47nH (tune) | L_0402_1005Metric | Murata | LQW15AN47NJ00 | yes
1 | L4 | 4.7nH | L_0402_1005Metric | Murata | LQP15MN4N7B02 | yes
4 | R1 R2 R3 R5 | 10k | R_0402_1005Metric |  |  | yes
1 | R4 | 1k | R_0402_1005Metric |  |  | yes
1 | SW1 | BOOT | SW_SPST_B3U-1000P | Omron | B3U-1000P | yes
1 | TP1 | 5V | TestPoint_Pad_D1.5mm |  |  | yes
1 | TP2 | GND | TestPoint_Pad_D1.5mm |  |  | yes
1 | TP3 | RX | TestPoint_Pad_D1.5mm |  |  | yes
1 | TP4 | TX | TestPoint_Pad_D1.5mm |  |  | yes
1 | TP5 | D+ | TestPoint_Pad_D1.0mm |  |  | yes
1 | TP6 | D- | TestPoint_Pad_D1.0mm |  |  | yes
1 | U1 | AP2112K-3.3TRG1 | SOT-23-5 | Diodes Inc | AP2112K-3.3TRG1 | yes
1 | U2 | ESP32-C3FH4 | QFN-32-1EP_5x5mm_P0.5mm_EP3.7x3.7mm | Espressif | ESP32-C3FH4 | yes
1 | U3 | SX1281IMLTRT | QFN-24-1EP_4x4mm_P0.5mm_EP2.6x2.6mm | Semtech | SX1281IMLTRT | yes
1 | Y1 | 40MHz 10pF | Crystal_SMD_2016-4Pin_2.0x1.6mm | Yangxing | X201640MLB4SI | yes
1 | Y2 | 52MHz 8pF | Crystal_SMD_2016-4Pin_2.0x1.6mm | Yangxing | X201652MOB4SI | yes
2 | C13 C14 | DNP | C_0402_1005Metric |  |  | DNP

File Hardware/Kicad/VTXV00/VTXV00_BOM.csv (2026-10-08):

Qty | References | Value | Footprint | Manufacturer | MPN | Populate
2 | C1 C3 | 22uF 10V | C_0805_2012Metric |  |  | yes
12 | C2 C6 C7 C9 C11 C13 C14 C15 C16 C17 C18 C30 | 100nF | C_0402_1005Metric |  |  | yes
1 | C4 | 1uF 16V | C_0402_1005Metric |  |  | yes
1 | C5 | 4.7uF 10V | C_0603_1608Metric |  |  | yes
4 | C8 C10 C21 C22 | 1uF | C_0402_1005Metric |  |  | yes
1 | C12 | 10uF 10V | C_0603_1608Metric |  |  | yes
4 | C19 C20 C25 C37 | 1nF | C_0402_1005Metric |  |  | yes
2 | C23 C24 | 18pF NP0 | C_0402_1005Metric |  |  | yes
3 | C26 C28 C29 | 10nF | C_0402_1005Metric |  |  | yes
1 | C27 | 470pF | C_0402_1005Metric |  |  | yes
4 | C32 C33 C38 C39 | 10pF NP0 | C_0402_1005Metric |  |  | yes
3 | C34 C35 C36 | 2.2uF | C_0402_1005Metric |  |  | yes
1 | D1 | RED | LED_0603_1608Metric |  |  | yes
1 | D2 | GREEN | LED_0603_1608Metric |  |  | yes
1 | D3 | BLUE | LED_0603_1608Metric |  |  | yes
1 | FB1 | 120R 3A | L_0603_1608Metric | Murata | BLM18KG121TN1D | yes
1 | FB2 | 120R@100MHz | L_0603_1608Metric |  | BLM18PG121SN1D | yes
1 | J1 | FC | JST_SH_SM06B-SRSS-TB_1x06-1MP_P1.00mm_Horizontal | JST | SM06B-SRSS-TB(LF)(SN) | yes
1 | J2 | U.FL | U.FL_Hirose_U.FL-R-SMT-1_Vertical | Hirose | U.FL-R-SMT-1(10) | yes
1 | L2 | 0R / tune | L_0402_1005Metric |  |  | yes
1 | Q1 | MMBT3904 | SOT-23 | onsemi | MMBT3904LT1G | yes
5 | R1 R7 R8 R11 R12 | 10k | R_0402_1005Metric |  |  | yes
2 | R2 R3 | 100R | R_0402_1005Metric |  |  | yes
4 | R4 R5 R6 R10 | 1k | R_0402_1005Metric |  |  | yes
1 | R9 | 4.7k | R_0402_1005Metric |  |  | yes
2 | R13 R19 | 0R | R_0402_1005Metric |  |  | yes
2 | R16 R18 | 97.6R | R_0402_1005Metric |  |  | yes
1 | R17 | 71.5R | R_0402_1005Metric |  |  | yes
1 | SW1 | BAND/CH | SW_SPST_B3U-1000P | Omron | B3U-1000P | yes
1 | TP1 | SWDIO | TestPoint_Pad_D1.0mm |  |  | yes
1 | TP2 | SWCLK | TestPoint_Pad_D1.0mm |  |  | yes
1 | TP3 | NRST | TestPoint_Pad_D1.0mm |  |  | yes
1 | TP4 | +3V3 | TestPoint_Pad_D1.0mm |  |  | yes
1 | TP5 | GND | TestPoint_Pad_D1.0mm |  |  | yes
1 | U1 | AP2112K-3.3TRG1 | SOT-23-5 | Diodes Inc | AP2112K-3.3TRG1 | yes
1 | U2 | STM32F031G6U6 | QFN-28_4x4mm_P0.5mm | STMicroelectronics | STM32F031G6U6 | yes
1 | U3 | RTC6705 | QFN-40-1EP_6x6mm_P0.5mm_EP4.6x4.6mm | RichWave | RTC6705 | yes
1 | U4 | RFPA5542 | QFN-20-1EP_4x4mm_P0.5mm_EP2.5x2.5mm | Qorvo | RFPA5542TR13 | yes
1 | Y1 | 8MHz 12pF | Crystal_SMD_3225-4Pin_3.2x2.5mm | Yangxing | X322508MLB4SI | yes
1 | C31 | 10uF (AC option) | C_0603_1608Metric |  |  | DNP
2 | C40 C41 | DNP | C_0402_1005Metric |  |  | DNP
1 | L1 | DNP (feed opt.) | L_0402_1005Metric |  |  | DNP
1 | R14 | 75R | R_0402_1005Metric |  |  | DNP
1 | R15 | 0R (high pwr) | R_0402_1005Metric |  |  | DNP

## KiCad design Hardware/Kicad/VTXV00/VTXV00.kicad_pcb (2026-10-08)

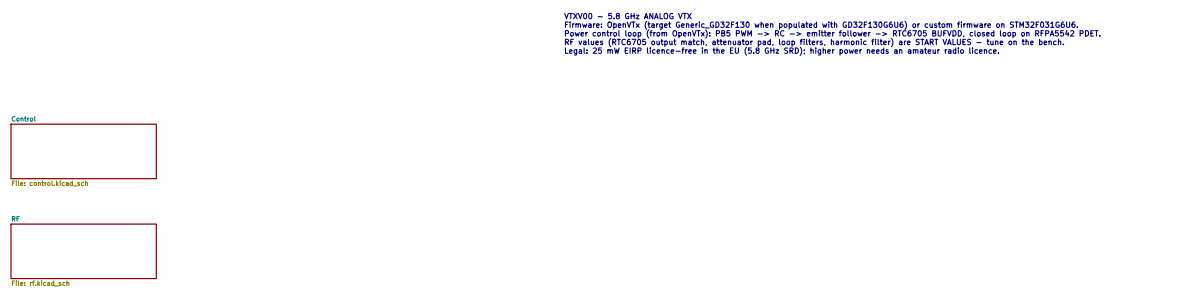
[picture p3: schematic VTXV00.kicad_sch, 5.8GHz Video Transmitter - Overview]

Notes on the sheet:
VTXV00 - 5.8 GHz ANALOG VTX Firmware: OpenVTx (target Generic_GD32F130 when populated with GD32F130G6U6) or custom firmware on STM32F031G6U6. Power control loop (from OpenVTx): PB5 PWM -> RC -> emitter follower -> RTC6705 BUFVDD, closed loop on RFPA5542 PDET. RF values (RTC6705 output match, attenu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

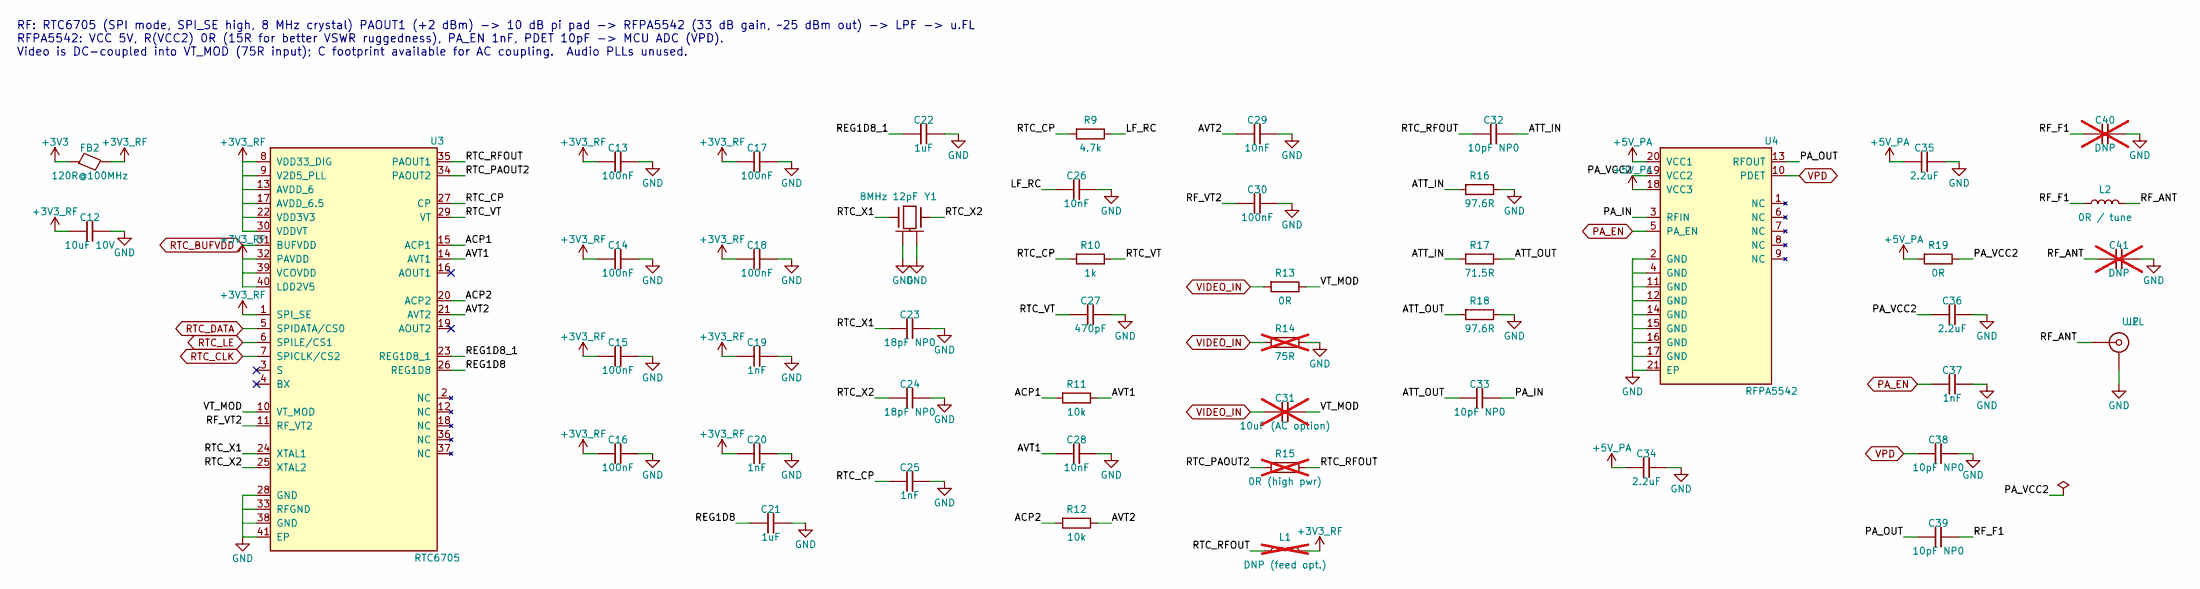
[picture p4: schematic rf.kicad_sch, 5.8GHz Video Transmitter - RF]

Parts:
C12: 10uF 10V; C_0603_1608Metric
C13, C14, C15, C16, C17, C18, C30: 100nF; C_0402_1005Metric
C19, C20, C25, C37: 1nF; C_0402_1005Metric
C21, C22: 1uF; C_0402_1005Metric
C23, C24: 18pF NP0; C_0402_1005Metric
C26, C28, C29: 10nF; C_0402_1005Metric
C27: 470pF; C_0402_1005Metric
C31: 10uF (AC option); C_0603_1608Metric; not fitted
C32, C33, C38, C39: 10pF NP0; C_0402_1005Metric
C34, C35, C36: 2.2uF; C_0402_1005Metric
C40, C41: DNP; C_0402_1005Metric; not fitted
FB2: 120R@100MHz; L_0603_1608Metric; MPN BLM18PG121SN1D
J2: U.FL; U.FL_Hirose_U.FL-R-SMT-1_Vertical; MPN U.FL-R-SMT-1(10)
L1: DNP (feed opt.); L_0402_1005Metric; not fitted
L2: 0R / tune; L_0402_1005Metric
R9: 4.7k; R_0402_1005Metric
R10: 1k; R_0402_1005Metric
R11, R12: 10k; R_0402_1005Metric
R13, R19: 0R; R_0402_1005Metric
R14: 75R; R_0402_1005Metric; not fitted
R15: 0R (high pwr); R_0402_1005Metric; not fitted
R16, R18: 97.6R; R_0402_1005Metric
R17: 71.5R; R_0402_1005Metric
U3: RTC6705; QFN-40-1EP_6x6mm_P0.5mm_EP4.6x4.6mm; MPN RTC6705
U4: RFPA5542; QFN-20-1EP_4x4mm_P0.5mm_EP2.5x2.5mm; MPN RFPA5542TR13
Y1: 8MHz 12pF; Crystal_SMD_3225-4Pin_3.2x2.5mm; MPN X322508MLB4SI

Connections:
+3V3: FB2.1; also elsewhere on the board
+3V3_RF: C12.1, C13.1, C14.1, C15.1, C16.1, C17.1, C18.1, C19.1, C20.1, FB2.2, L1.2, U3.1 (SPI_SE), U3.8 (VDD33_DIG), U3.9 (V2D5_PLL), U3.13 (AVDD_6), U3.17 (AVDD_6.5), U3.22 (VDD3V3), U3.30 (VDDVT), U3.32 (PAVDD), U3.39 (VCOVDD), U3.40 (LDD2V5); also elsewhere on the board
+5V_PA: C34.1, C35.1, R19.1, U4.18 (VCC3), U4.20 (VCC1); also elsewhere on the board
/RF/ACP1: R11.1, U3.15 (ACP1)
/RF/ACP2: R12.1, U3.20 (ACP2)
/RF/ATT_IN: C32.2, R16.1, R17.1
/RF/ATT_OUT: C33.1, R17.2, R18.1
/RF/AVT1: C28.1, R11.2, U3.14 (AVT1)
/RF/AVT2: C29.1, R12.2, U3.21 (AVT2)
/RF/LF_RC: C26.1, R9.2
/RF/PA_IN: C33.2, U4.3 (RFIN)
/RF/PA_OUT: C39.1, U4.13 (RFOUT)
/RF/PA_VCC2: C36.1, R19.2, U4.19 (VCC2)
/RF/REG1D8: C21.1, U3.26 (REG1D8)
/RF/REG1D8_1: C22.1, U3.23 (REG1D8_1)
/RF/RF_ANT: C41.1, J2.1 (In), L2.2
/RF/RF_F1: C39.2, C40.1, L2.1
/RF/RF_VT2: C30.1, U3.11 (RF_VT2)
/RF/RTC_CP: C25.1, R9.1, R10.1, U3.27 (CP)
/RF/RTC_PAOUT2: R15.1, U3.34 (PAOUT2)
/RF/RTC_RFOUT: C32.1, L1.1, R15.2, U3.35 (PAOUT1)
/RF/RTC_VT: C27.1, R10.2, U3.29 (VT)
/RF/RTC_X1: C23.1, U3.24 (XTAL1), Y1.1
/RF/RTC_X2: C24.1, U3.25 (XTAL2), Y1.3
/RF/VT_MOD: C31.2, R13.2, U3.10 (VT_MOD)
GND: C12.2, C13.2, C14.2, C15.2, C16.2, C17.2, C18.2, C19.2, C20.2, C21.2, C22.2, C23.2, C24.2, C25.2, C26.2, C27.2, C28.2, C29.2, C30.2, C34.2, C35.2, C36.2, C37.2, C38.2, C40.2, C41.2, J2.2 (Ext), R14.2, R16.2, R18.2, U3.28 (GND), U3.33 (RFGND), U3.38 (GND), U3.41 (EP), U4.2 (GND), U4.4 (GND), U4.11 (GND), U4.12 (GND), U4.14 (GND), U4.15 (GND), U4.16 (GND), U4.17 (GND), U4.21 (EP), Y1.2 (GND), Y1.4 (GND); also elsewhere on the board
PA_EN: C37.1, U4.5 (PA_EN); also elsewhere on the board
RTC_BUFVDD: U3.31 (BUFVDD); also elsewhere on the board
RTC_CLK: U3.7 (SPICLK/CS2); also elsewhere on the board
RTC_DATA: U3.5 (SPIDATA/CS0); also elsewhere on the board
RTC_LE: U3.6 (SPILE/CS1); also elsewhere on the board
VIDEO_IN: C31.1, R13.1, R14.1; also elsewhere on the board
VPD: C38.1, U4.10 (PDET); also elsewhere on the board

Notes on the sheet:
RF: RTC6705 (SPI mode, SPI_SE high, 8 MHz crystal) PAOUT1 (+2 dBm) -> 10 dB pi pad -> RFPA5542 (33 dB gain, ~25 dBm out) -> LPF -> u.FL RFPA5542: VCC 5V, R(VCC2) 0R (15R for better VSWR ruggedness), PA_EN 1nF, PDET 10pF -> MCU ADC (VPD). Video is DC-coupled into VT_MOD (75R input); C footprint avai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

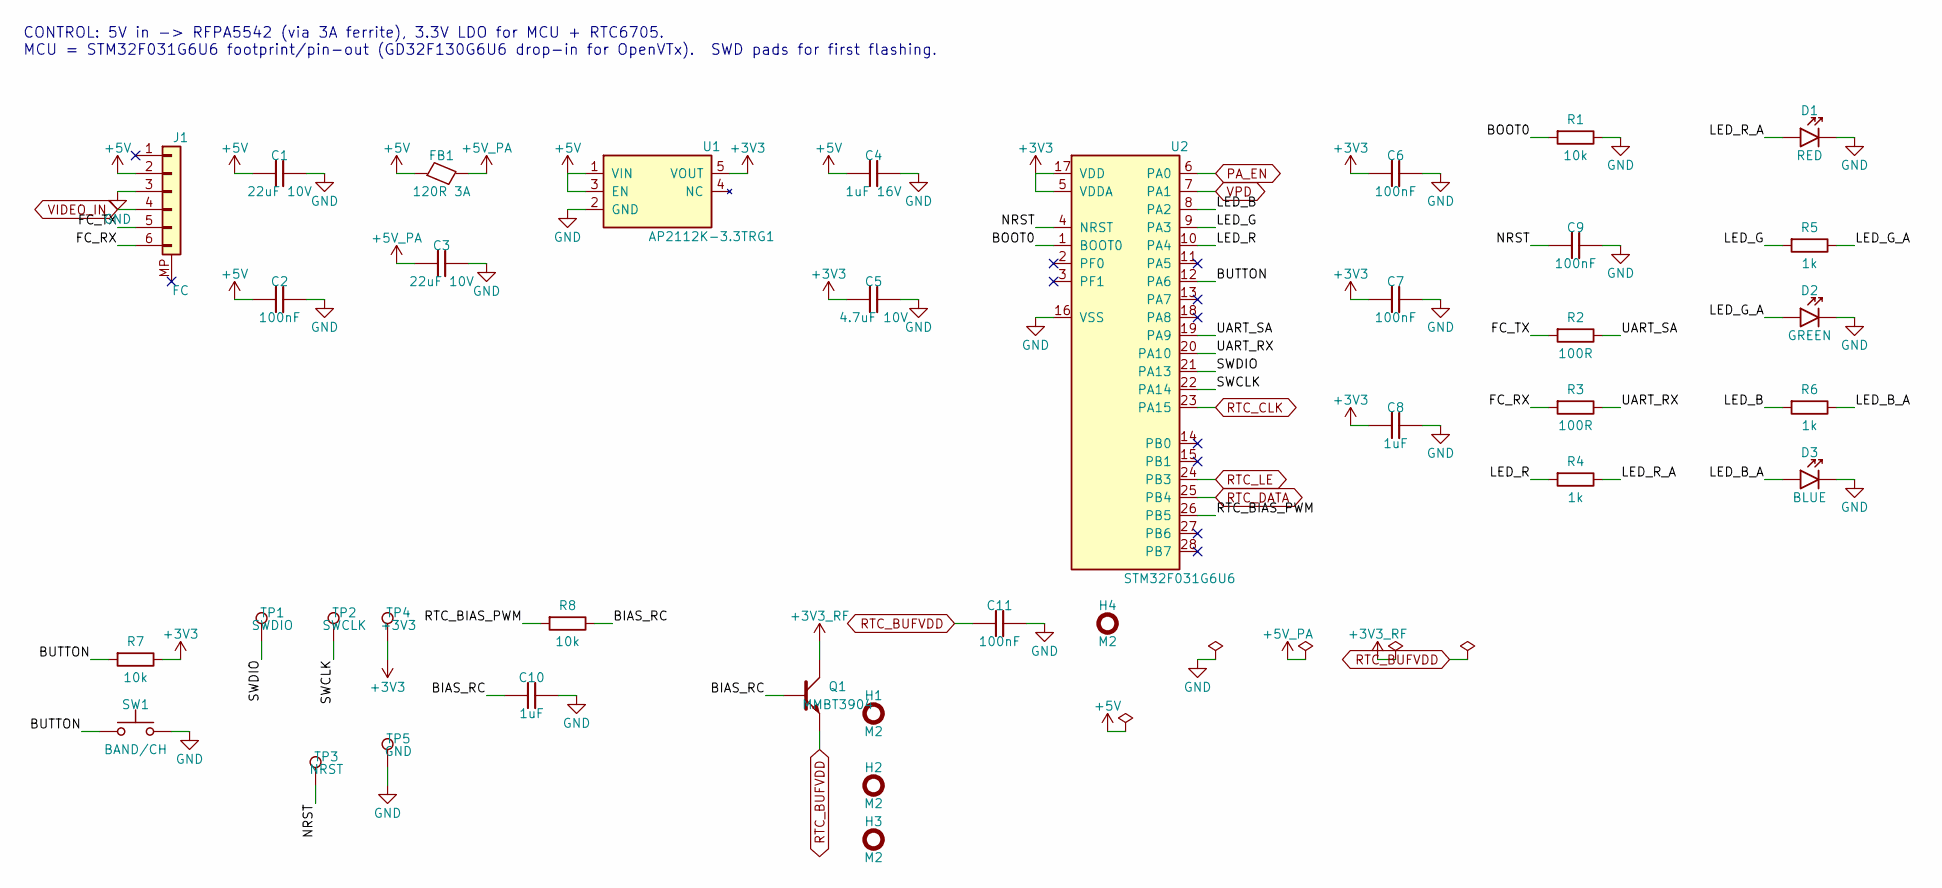
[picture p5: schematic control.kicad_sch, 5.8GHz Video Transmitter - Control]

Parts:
C1, C3: 22uF 10V; C_0805_2012Metric
C2, C6, C7, C9, C11: 100nF; C_0402_1005Metric
C4: 1uF 16V; C_0402_1005Metric
C5: 4.7uF 10V; C_0603_1608Metric
C8, C10: 1uF; C_0402_1005Metric
D1: RED; LED_0603_1608Metric
D2: GREEN; LED_0603_1608Metric
D3: BLUE; LED_0603_1608Metric
FB1: 120R 3A; L_0603_1608Metric; MPN BLM18KG121TN1D
H1, H2, H3, H4: M2; MountingHole_2.2mm_M2
J1: FC; JST_SH_SM06B-SRSS-TB_1x06-1MP_P1.00mm_Horizontal; MPN SM06B-SRSS-TB(LF)(SN)
Q1: MMBT3904; SOT-23; MPN MMBT3904LT1G; LCSC C20526
R1, R7, R8: 10k; R_0402_1005Metric
R2, R3: 100R; R_0402_1005Metric
R4, R5, R6: 1k; R_0402_1005Metric
SW1: BAND/CH; SW_SPST_B3U-1000P; MPN B3U-1000P
TP1: SWDIO; TestPoint_Pad_D1.0mm
TP2: SWCLK; TestPoint_Pad_D1.0mm
TP3: NRST; TestPoint_Pad_D1.0mm
TP4: +3V3; TestPoint_Pad_D1.0mm
TP5: GND; TestPoint_Pad_D1.0mm
U1: AP2112K-3.3TRG1; SOT-23-5; MPN AP2112K-3.3TRG1; LCSC C51118
U2: STM32F031G6U6; QFN-28_4x4mm_P0.5mm; MPN STM32F031G6U6

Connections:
+3V3: C5.1, C6.1, C7.1, C8.1, R7.2, TP4.1, U1.5 (VOUT), U2.5 (VDDA), U2.17 (VDD); also elsewhere on the board
+3V3_RF: Q1.3 (C); also elsewhere on the board
+5V: C1.1, C2.1, C4.1, FB1.1, J1.2, U1.1 (VIN), U1.3 (EN)
+5V_PA: C3.1, FB1.2; also elsewhere on the board
/Control/BIAS_RC: C10.1, Q1.1 (B), R8.2
/Control/BOOT0: R1.1, U2.1 (BOOT0)
/Control/BUTTON: R7.1, SW1.1, U2.12 (PA6)
/Control/FC_RX: J1.6, R3.1
/Control/FC_TX: J1.5, R2.1
/Control/LED_B: R6.1, U2.8 (PA2)
/Control/LED_B_A: D3.2 (A), R6.2
/Control/LED_G: R5.1, U2.9 (PA3)
/Control/LED_G_A: D2.2 (A), R5.2
/Control/LED_R: R4.1, U2.10 (PA4)
/Control/LED_R_A: D1.2 (A), R4.2
/Control/NRST: C9.1, TP3.1, U2.4 (NRST)
/Control/RTC_BIAS_PWM: R8.1, U2.26 (PB5)
/Control/SWCLK: TP2.1, U2.22 (PA14)
/Control/SWDIO: TP1.1, U2.21 (PA13)
/Control/UART_RX: R3.2, U2.20 (PA10)
/Control/UART_SA: R2.2, U2.19 (PA9)
GND: C1.2, C2.2, C3.2, C4.2, C5.2, C6.2, C7.2, C8.2, C9.2, C10.2, C11.2, D1.1 (K), D2.1 (K), D3.1 (K), J1.3, R1.2, SW1.2, TP5.1, U1.2 (GND), U2.16 (VSS); also elsewhere on the board
PA_EN: U2.6 (PA0); also elsewhere on the board
RTC_BUFVDD: C11.1, Q1.2 (E); also elsewhere on the board
RTC_CLK: U2.23 (PA15); also elsewhere on the board
RTC_DATA: U2.25 (PB4); also elsewhere on the board
RTC_LE: U2.24 (PB3); also elsewhere on the board
VIDEO_IN: J1.4; also elsewhere on the board
VPD: U2.7 (PA1); also elsewhere on the board

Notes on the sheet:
CONTROL: 5V in -> RFPA5542 (via 3A ferrite), 3.3V LDO for MCU + RTC6705. MCU = STM32F031G6U6 footprint/pin-out (GD32F130G6U6 drop-in for OpenVTx). SWD pads for first flashing.

Board: 4 copper layers, 85 parts (0 on the bottom side), 51 nets, no tracks yet.

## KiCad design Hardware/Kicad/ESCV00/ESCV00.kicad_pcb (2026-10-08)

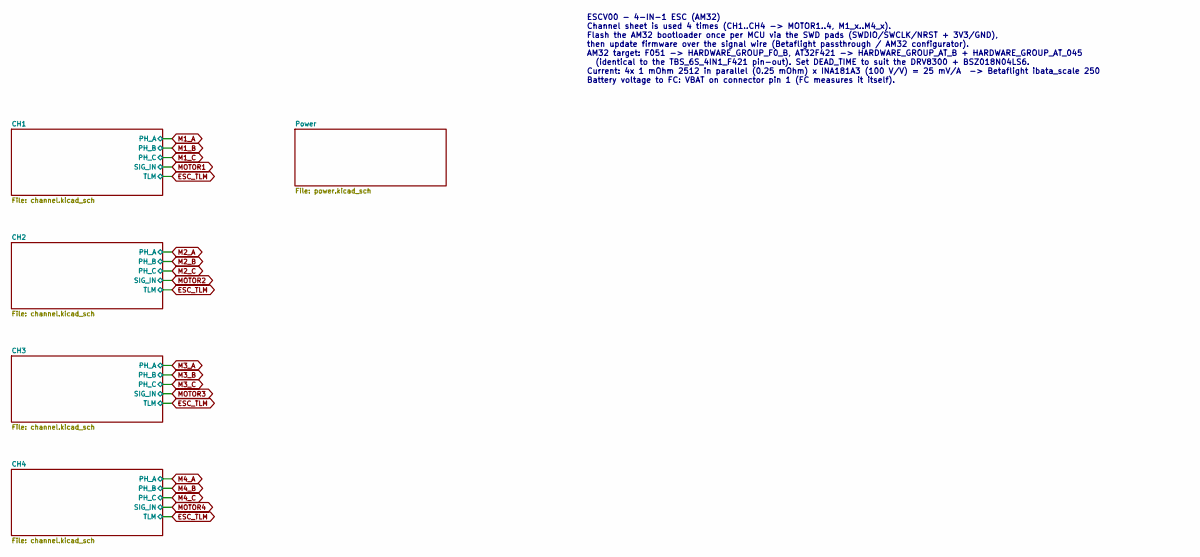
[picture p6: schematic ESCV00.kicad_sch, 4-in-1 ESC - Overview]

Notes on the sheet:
ESCV00 - 4-IN-1 ESC (AM32) Channel sheet is used 4 times (CH1..CH4 -> MOTOR1..4, M1_x..M4_x). Flash the AM32 bootloader once per MCU via the SWD pads (SWDIO/SWCLK/NRST + 3V3/GND), then update firmware over the signal wire (Betaflight passthrough / AM32 configurator). AM32 target: F051 -> HARDWARE_G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

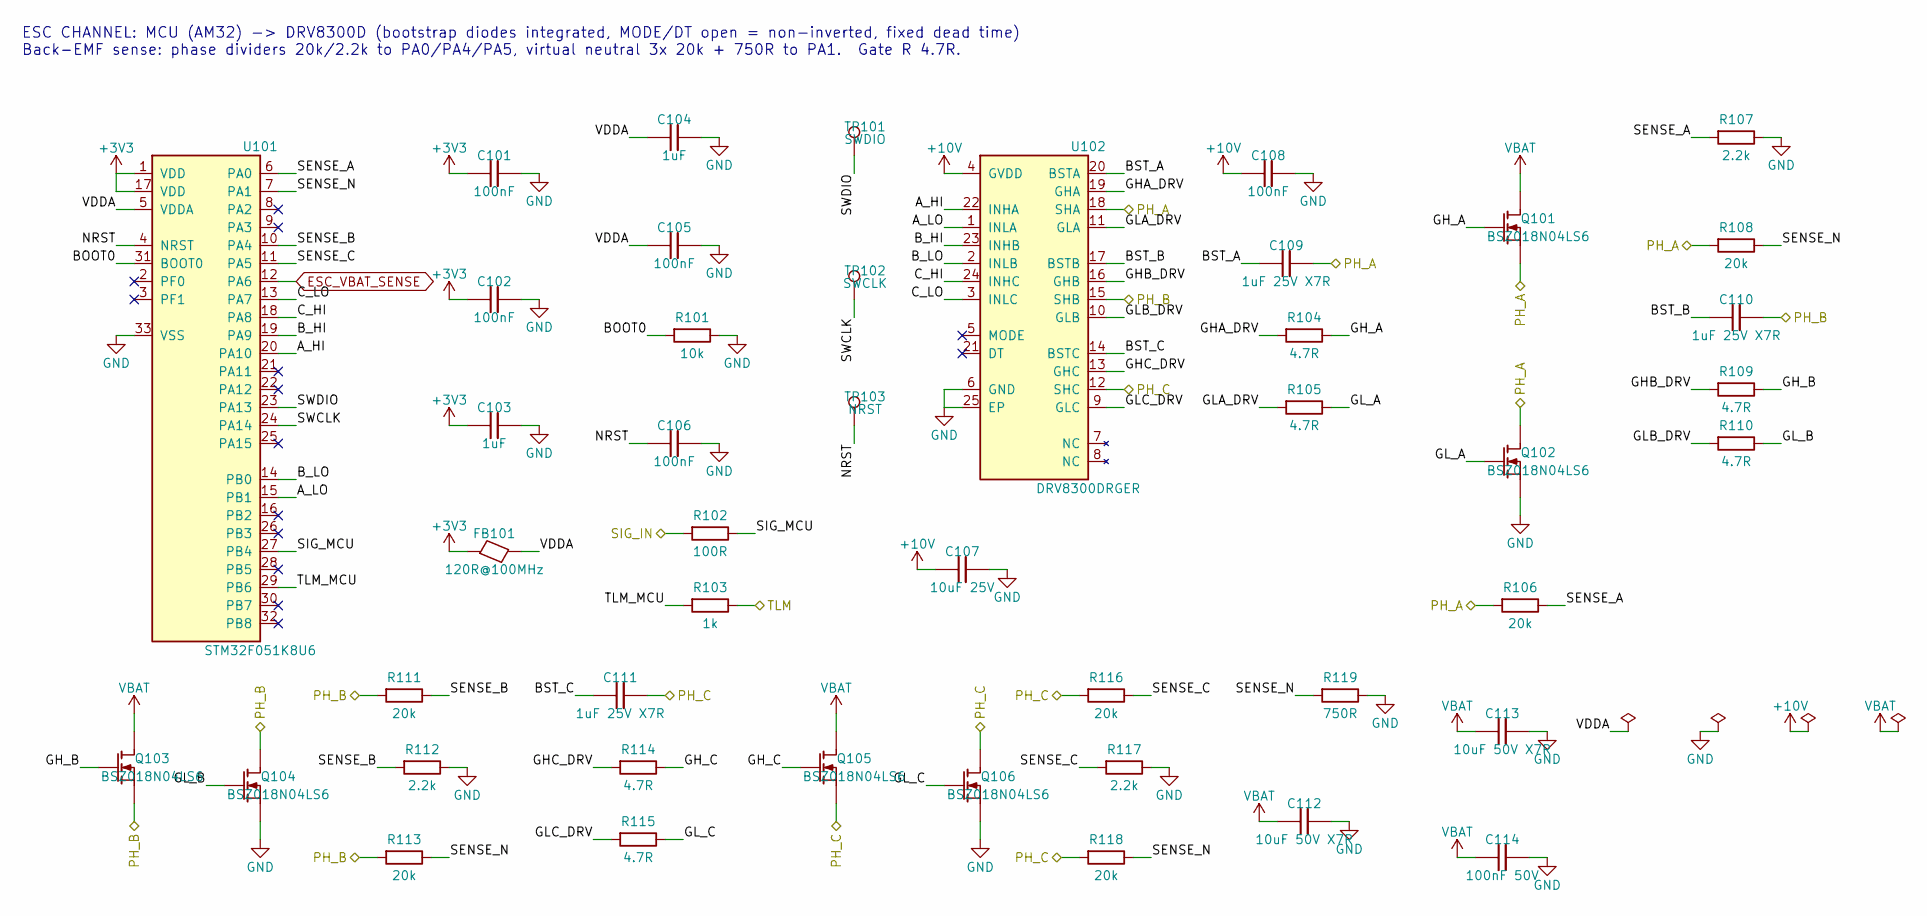
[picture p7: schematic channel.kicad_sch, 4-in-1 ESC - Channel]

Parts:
C101, C102, C105, C106, C108: 100nF; C_0402_1005Metric
C103, C104: 1uF; C_0402_1005Metric
C107: 10uF 25V; C_0805_2012Metric
C109, C110, C111: 1uF 25V X7R; C_0603_1608Metric
C112, C113: 10uF 50V X7R; C_1206_3216Metric
C114: 100nF 50V; C_0603_1608Metric
FB101: 120R@100MHz; L_0402_1005Metric; MPN BLM15PX121SN1D
Q101, Q102, Q103, Q104, Q105, Q106: BSZ018N04LS6; PQFN-8_3.3x3.3mm_P0.65mm_PowerFET; MPN BSZ018N04LS6ATMA1
R101: 10k; R_0402_1005Metric
R102: 100R; R_0402_1005Metric
R103: 1k; R_0402_1005Metric
R104, R105, R109, R110, R114, R115: 4.7R; R_0402_1005Metric
R106, R108, R111, R113, R116, R118: 20k; R_0402_1005Metric
R107, R112, R117: 2.2k; R_0402_1005Metric
R119: 750R; R_0402_1005Metric
TP101: SWDIO; TestPoint_Pad_D1.0mm
TP102: SWCLK; TestPoint_Pad_D1.0mm
TP103: NRST; TestPoint_Pad_D1.0mm
U101: STM32F051K8U6; QFN-32-1EP_5x5mm_P0.5mm_EP3.45x3.45mm; MPN STM32F051K8U6
U102: DRV8300DRGER; VQFN-24-1EP_4x4mm_P0.5mm_EP2.45x2.45mm; MPN DRV8300DRGER

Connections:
+3V3: C101.1, C102.1, C103.1, FB101.1, U101.1 (VDD), U101.17 (VDD); also elsewhere on the board
+10V: C107.1, C108.1, U102.4 (GVDD); also elsewhere on the board
/CH1/A_HI: U101.20 (PA10), U102.22 (INHA)
/CH1/A_LO: U101.15 (PB1), U102.1 (INLA)
/CH1/BOOT0: R101.1, U101.31 (BOOT0)
/CH1/BST_A: C109.1, U102.20 (BSTA)
/CH1/BST_B: C110.1, U102.17 (BSTB)
/CH1/BST_C: C111.1, U102.14 (BSTC)
/CH1/B_HI: U101.19 (PA9), U102.23 (INHB)
/CH1/B_LO: U101.14 (PB0), U102.2 (INLB)
/CH1/C_HI: U101.18 (PA8), U102.24 (INHC)
/CH1/C_LO: U101.13 (PA7), U102.3 (INLC)
/CH1/GHA_DRV: R104.1, U102.19 (GHA)
/CH1/GHB_DRV: R109.1, U102.16 (GHB)
/CH1/GHC_DRV: R114.1, U102.13 (GHC)
/CH1/GH_A: Q101.4 (G), R104.2
/CH1/GH_B: Q103.4 (G), R109.2
/CH1/GH_C: Q105.4 (G), R114.2
/CH1/GLA_DRV: R105.1, U102.11 (GLA)
/CH1/GLB_DRV: R110.1, U102.10 (GLB)
/CH1/GLC_DRV: R115.1, U102.9 (GLC)
/CH1/GL_A: Q102.4 (G), R105.2
/CH1/GL_B: Q104.4 (G), R110.2
/CH1/GL_C: Q106.4 (G), R115.2
/CH1/NRST: C106.1, TP103.1, U101.4 (NRST)
/CH1/SENSE_A: R106.2, R107.1, U101.6 (PA0)
/CH1/SENSE_B: R111.2, R112.1, U101.10 (PA4)
/CH1/SENSE_C: R116.2, R117.1, U101.11 (PA5)
/CH1/SENSE_N: R108.2, R113.2, R118.2, R119.1, U101.7 (PA1)
/CH1/SIG_MCU: R102.2, U101.27 (PB4)
/CH1/SWCLK: TP102.1, U101.24 (PA14)
/CH1/SWDIO: TP101.1, U101.23 (PA13)
/CH1/TLM_MCU: R103.1, U101.29 (PB6)
/CH1/VDDA: C104.1, C105.1, FB101.2, U101.5 (VDDA)
ESC_TLM: R103.2; also elsewhere on the board
ESC_VBAT_SENSE: U101.12 (PA6); also elsewhere on the board
GND: C101.2, C102.2, C103.2, C104.2, C105.2, C106.2, C107.2, C108.2, C112.2, C113.2, C114.2, Q102.1 (S), Q102.2 (S), Q102.3 (S), Q104.1 (S), Q104.2 (S), Q104.3 (S), Q106.1 (S), Q106.2 (S), Q106.3 (S), R101.2, R107.2, R112.2, R117.2, R119.2, U101.33 (VSS), U102.6 (GND), U102.25 (EP); also elsewhere on the board
M1_A: C109.2, Q101.1 (S), Q101.2 (S), Q101.3 (S), Q102.5 (D), R106.1, R108.1, U102.18 (SHA); also elsewhere on the board
M1_B: C110.2, Q103.1 (S), Q103.2 (S), Q103.3 (S), Q104.5 (D), R111.1, R113.1, U102.15 (SHB); also elsewhere on the board
M1_C: C111.2, Q105.1 (S), Q105.2 (S), Q105.3 (S), Q106.5 (D), R116.1, R118.1, U102.12 (SHC); also elsewhere on the board
MOTOR1: R102.1; also elsewhere on the board
VBAT: C112.1, C113.1, C114.1, Q101.5 (D), Q103.5 (D), Q105.5 (D); also elsewhere on the board

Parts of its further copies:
C201, C202, C205, C206, C208, C301, C302, C305, C306, C308, C401, C402, C405, C406, C408: 100nF; C_0402_1005Metric
C203, C204, C303, C304, C403, C404: 1uF; C_0402_1005Metric
C207, C307, C407: 10uF 25V; C_0805_2012Metric
C209, C210, C211, C309, C310, C311, C409, C410, C411: 1uF 25V X7R; C_0603_1608Metric
C212, C213, C312, C313, C412, C413: 10uF 50V X7R; C_1206_3216Metric
C214, C314, C414: 100nF 50V; C_0603_1608Metric
FB201, FB301, FB401: 120R@100MHz; L_0402_1005Metric; MPN BLM15PX121SN1D
Q201, Q202, Q203, Q204, Q205, Q206, Q301, Q302, Q303, Q304, Q305, Q306, Q401, Q402, Q403, Q404, Q405, Q406: BSZ018N04LS6; PQFN-8_3.3x3.3mm_P0.65mm_PowerFET; MPN BSZ018N04LS6ATMA1
R201, R301, R401: 10k; R_0402_1005Metric
R202, R302, R402: 100R; R_0402_1005Metric
R203, R303, R403: 1k; R_0402_1005Metric
R204, R205, R209, R210, R214, R215, R304, R305, R309, R310, R314, R315, R404, R405, R409, R410, R414, R415: 4.7R; R_0402_1005Metric
R206, R208, R211, R213, R216, R218, R306, R308, R311, R313, R316, R318, R406, R408, R411, R413, R416, R418: 20k; R_0402_1005Metric
R207, R212, R217, R307, R312, R317, R407, R412, R417: 2.2k; R_0402_1005Metric
R219, R319, R419: 750R; R_0402_1005Metric
TP201, TP301, TP401: SWDIO; TestPoint_Pad_D1.0mm
TP202, TP302, TP402: SWCLK; TestPoint_Pad_D1.0mm
TP203, TP303, TP403: NRST; TestPoint_Pad_D1.0mm
U201, U301, U401: STM32F051K8U6; QFN-32-1EP_5x5mm_P0.5mm_EP3.45x3.45mm; MPN STM32F051K8U6
U202, U302, U402: DRV8300DRGER; VQFN-24-1EP_4x4mm_P0.5mm_EP2.45x2.45mm; MPN DRV8300DRGER

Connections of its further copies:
+3V3: C201.1, C202.1, C203.1, C301.1, C302.1, C303.1, C401.1, C402.1, C403.1, FB201.1, FB301.1, FB401.1, U201.1 (VDD), U201.17 (VDD), U301.1 (VDD), U301.17 (VDD), U401.1 (VDD), U401.17 (VDD); also elsewhere on the board
+10V: C207.1, C208.1, C307.1, C308.1, C407.1, C408.1, U202.4 (GVDD), U302.4 (GVDD), U402.4 (GVDD); also elsewhere on the board
/CH2/A_HI: U201.20 (PA10), U202.22 (INHA)
/CH2/A_LO: U201.15 (PB1), U202.1 (INLA)
/CH2/BOOT0: R201.1, U201.31 (BOOT0)
/CH2/BST_A: C209.1, U202.20 (BSTA)
/CH2/BST_B: C210.1, U202.17 (BSTB)
/CH2/BST_C: C211.1, U202.14 (BSTC)
/CH2/B_HI: U201.19 (PA9), U202.23 (INHB)
/CH2/B_LO: U201.14 (PB0), U202.2 (INLB)
/CH2/C_HI: U201.18 (PA8), U202.24 (INHC)
/CH2/C_LO: U201.13 (PA7), U202.3 (INLC)
/CH2/GHA_DRV: R204.1, U202.19 (GHA)
/CH2/GHB_DRV: R209.1, U202.16 (GHB)
/CH2/GHC_DRV: R214.1, U202.13 (GHC)
/CH2/GH_A: Q201.4 (G), R204.2
/CH2/GH_B: Q203.4 (G), R209.2
/CH2/GH_C: Q205.4 (G), R214.2
/CH2/GLA_DRV: R205.1, U202.11 (GLA)
/CH2/GLB_DRV: R210.1, U202.10 (GLB)
/CH2/GLC_DRV: R215.1, U202.9 (GLC)
/CH2/GL_A: Q202.4 (G), R205.2
/CH2/GL_B: Q204.4 (G), R210.2
/CH2/GL_C: Q206.4 (G), R215.2
/CH2/NRST: C206.1, TP203.1, U201.4 (NRST)
/CH2/SENSE_A: R206.2, R207.1, U201.6 (PA0)
/CH2/SENSE_B: R211.2, R212.1, U201.10 (PA4)
/CH2/SENSE_C: R216.2, R217.1, U201.11 (PA5)
/CH2/SENSE_N: R208.2, R213.2, R218.2, R219.1, U201.7 (PA1)
/CH2/SIG_MCU: R202.2, U201.27 (PB4)
/CH2/SWCLK: TP202.1, U201.24 (PA14)
/CH2/SWDIO: TP201.1, U201.23 (PA13)
/CH2/TLM_MCU: R203.1, U201.29 (PB6)
/CH2/VDDA: C204.1, C205.1, FB201.2, U201.5 (VDDA)
/CH3/A_HI: U301.20 (PA10), U302.22 (INHA)
/CH3/A_LO: U301.15 (PB1), U302.1 (INLA)
/CH3/BOOT0: R301.1, U301.31 (BOOT0)
/CH3/BST_A: C309.1, U302.20 (BSTA)
/CH3/BST_B: C310.1, U302.17 (BSTB)
/CH3/BST_C: C311.1, U302.14 (BSTC)
/CH3/B_HI: U301.19 (PA9), U302.23 (INHB)
/CH3/B_LO: U301.14 (PB0), U302.2 (INLB)
/CH3/C_HI: U301.18 (PA8), U302.24 (INHC)
/CH3/C_LO: U301.13 (PA7), U302.3 (INLC)
/CH3/GHA_DRV: R304.1, U302.19 (GHA)
/CH3/GHB_DRV: R309.1, U302.16 (GHB)
/CH3/GHC_DRV: R314.1, U302.13 (GHC)
/CH3/GH_A: Q301.4 (G), R304.2
/CH3/GH_B: Q303.4 (G), R309.2
/CH3/GH_C: Q305.4 (G), R314.2
/CH3/GLA_DRV: R305.1, U302.11 (GLA)
/CH3/GLB_DRV: R310.1, U302.10 (GLB)
/CH3/GLC_DRV: R315.1, U302.9 (GLC)
/CH3/GL_A: Q302.4 (G), R305.2
/CH3/GL_B: Q304.4 (G), R310.2
/CH3/GL_C: Q306.4 (G), R315.2
/CH3/NRST: C306.1, TP303.1, U301.4 (NRST)
/CH3/SENSE_A: R306.2, R307.1, U301.6 (PA0)
/CH3/SENSE_B: R311.2, R312.1, U301.10 (PA4)
/CH3/SENSE_C: R316.2, R317.1, U301.11 (PA5)
/CH3/SENSE_N: R308.2, R313.2, R318.2, R319.1, U301.7 (PA1)
/CH3/SIG_MCU: R302.2, U301.27 (PB4)
/CH3/SWCLK: TP302.1, U301.24 (PA14)
/CH3/SWDIO: TP301.1, U301.23 (PA13)
/CH3/TLM_MCU: R303.1, U301.29 (PB6)
/CH3/VDDA: C304.1, C305.1, FB301.2, U301.5 (VDDA)
/CH4/A_HI: U401.20 (PA10), U402.22 (INHA)
/CH4/A_LO: U401.15 (PB1), U402.1 (INLA)
/CH4/BOOT0: R401.1, U401.31 (BOOT0)
/CH4/BST_A: C409.1, U402.20 (BSTA)
/CH4/BST_B: C410.1, U402.17 (BSTB)
/CH4/BST_C: C411.1, U402.14 (BSTC)
/CH4/B_HI: U401.19 (PA9), U402.23 (INHB)
/CH4/B_LO: U401.14 (PB0), U402.2 (INLB)
/CH4/C_HI: U401.18 (PA8), U402.24 (INHC)
/CH4/C_LO: U401.13 (PA7), U402.3 (INLC)
/CH4/GHA_DRV: R404.1, U402.19 (GHA)
/CH4/GHB_DRV: R409.1, U402.16 (GHB)
/CH4/GHC_DRV: R414.1, U402.13 (GHC)
/CH4/GH_A: Q401.4 (G), R404.2
/CH4/GH_B: Q403.4 (G), R409.2
/CH4/GH_C: Q405.4 (G), R414.2
/CH4/GLA_DRV: R405.1, U402.11 (GLA)
/CH4/GLB_DRV: R410.1, U402.10 (GLB)
/CH4/GLC_DRV: R415.1, U402.9 (GLC)
/CH4/GL_A: Q402.4 (G), R405.2
/CH4/GL_B: Q404.4 (G), R410.2
/CH4/GL_C: Q406.4 (G), R415.2
/CH4/NRST: C406.1, TP403.1, U401.4 (NRST)
/CH4/SENSE_A: R406.2, R407.1, U401.6 (PA0)
/CH4/SENSE_B: R411.2, R412.1, U401.10 (PA4)
/CH4/SENSE_C: R416.2, R417.1, U401.11 (PA5)
/CH4/SENSE_N: R408.2, R413.2, R418.2, R419.1, U401.7 (PA1)
/CH4/SIG_MCU: R402.2, U401.27 (PB4)
/CH4/SWCLK: TP402.1, U401.24 (PA14)
/CH4/SWDIO: TP401.1, U401.23 (PA13)
/CH4/TLM_MCU: R403.1, U401.29 (PB6)
/CH4/VDDA: C404.1, C405.1, FB401.2, U401.5 (VDDA)
ESC_TLM: R203.2, R303.2, R403.2; also elsewhere on the board
ESC_VBAT_SENSE: U201.12 (PA6), U301.12 (PA6), U401.12 (PA6); also elsewhere on the board
GND: C201.2, C202.2, C203.2, C204.2, C205.2, C206.2, C207.2, C208.2, C212.2, C213.2, C214.2, C301.2, C302.2, C303.2, C304.2, C305.2, C306.2, C307.2, C308.2, C312.2, C313.2, C314.2, C401.2, C402.2, C403.2, C404.2, C405.2, C406.2, C407.2, C408.2, C412.2, C413.2, C414.2, Q202.1 (S), Q202.2 (S), Q202.3 (S), Q204.1 (S), Q204.2 (S), Q204.3 (S), Q206.1 (S), Q206.2 (S), Q206.3 (S), Q302.1 (S), Q302.2 (S), Q302.3 (S), Q304.1 (S), Q304.2 (S), Q304.3 (S), Q306.1 (S), Q306.2 (S), Q306.3 (S), Q402.1 (S), Q402.2 (S), Q402.3 (S), Q404.1 (S), Q404.2 (S), Q404.3 (S), Q406.1 (S), Q406.2 (S), Q406.3 (S), R201.2, R207.2, R212.2, R217.2, R219.2, R301.2, R307.2, R312.2, R317.2, R319.2, R401.2, R407.2, R412.2, R417.2, R419.2, U201.33 (VSS), U202.6 (GND), U202.25 (EP), U301.33 (VSS), U302.6 (GND), U302.25 (EP), U401.33 (VSS), U402.6 (GND), U402.25 (EP); also elsewhere on the board
M2_A: C209.2, Q201.1 (S), Q201.2 (S), Q201.3 (S), Q202.5 (D), R206.1, R208.1, U202.18 (SHA); also elsewhere on the board
M2_B: C210.2, Q203.1 (S), Q203.2 (S), Q203.3 (S), Q204.5 (D), R211.1, R213.1, U202.15 (SHB); also elsewhere on the board
M2_C: C211.2, Q205.1 (S), Q205.2 (S), Q205.3 (S), Q206.5 (D), R216.1, R218.1, U202.12 (SHC); also elsewhere on the board
M3_A: C309.2, Q301.1 (S), Q301.2 (S), Q301.3 (S), Q302.5 (D), R306.1, R308.1, U302.18 (SHA); also elsewhere on the board
M3_B: C310.2, Q303.1 (S), Q303.2 (S), Q303.3 (S), Q304.5 (D), R311.1, R313.1, U302.15 (SHB); also elsewhere on the board
M3_C: C311.2, Q305.1 (S), Q305.2 (S), Q305.3 (S), Q306.5 (D), R316.1, R318.1, U302.12 (SHC); also elsewhere on the board
M4_A: C409.2, Q401.1 (S), Q401.2 (S), Q401.3 (S), Q402.5 (D), R406.1, R408.1, U402.18 (SHA); also elsewhere on the board
M4_B: C410.2, Q403.1 (S), Q403.2 (S), Q403.3 (S), Q404.5 (D), R411.1, R413.1, U402.15 (SHB); also elsewhere on the board
M4_C: C411.2, Q405.1 (S), Q405.2 (S), Q405.3 (S), Q406.5 (D), R416.1, R418.1, U402.12 (SHC); also elsewhere on the board
MOTOR2: R202.1; also elsewhere on the board
MOTOR3: R302.1; also elsewhere on the board
MOTOR4: R402.1; also elsewhere on the board
VBAT: C212.1, C213.1, C214.1, C312.1, C313.1, C314.1, C412.1, C413.1, C414.1, Q201.5 (D), Q203.5 (D), Q205.5 (D), Q301.5 (D), Q303.5 (D), Q305.5 (D), Q401.5 (D), Q403.5 (D), Q405.5 (D); also elsewhere on the board

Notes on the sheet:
ESC CHANNEL: MCU (AM32) -> DRV8300D (bootstrap diodes integrated, MODE/DT open = non-inverted, fixed dead time) Back-EMF sense: phase dividers 20k/2.2k to PA0/PA4/PA5, virtual neutral 3x 20k + 750R to PA1. Gate R 4.7R.

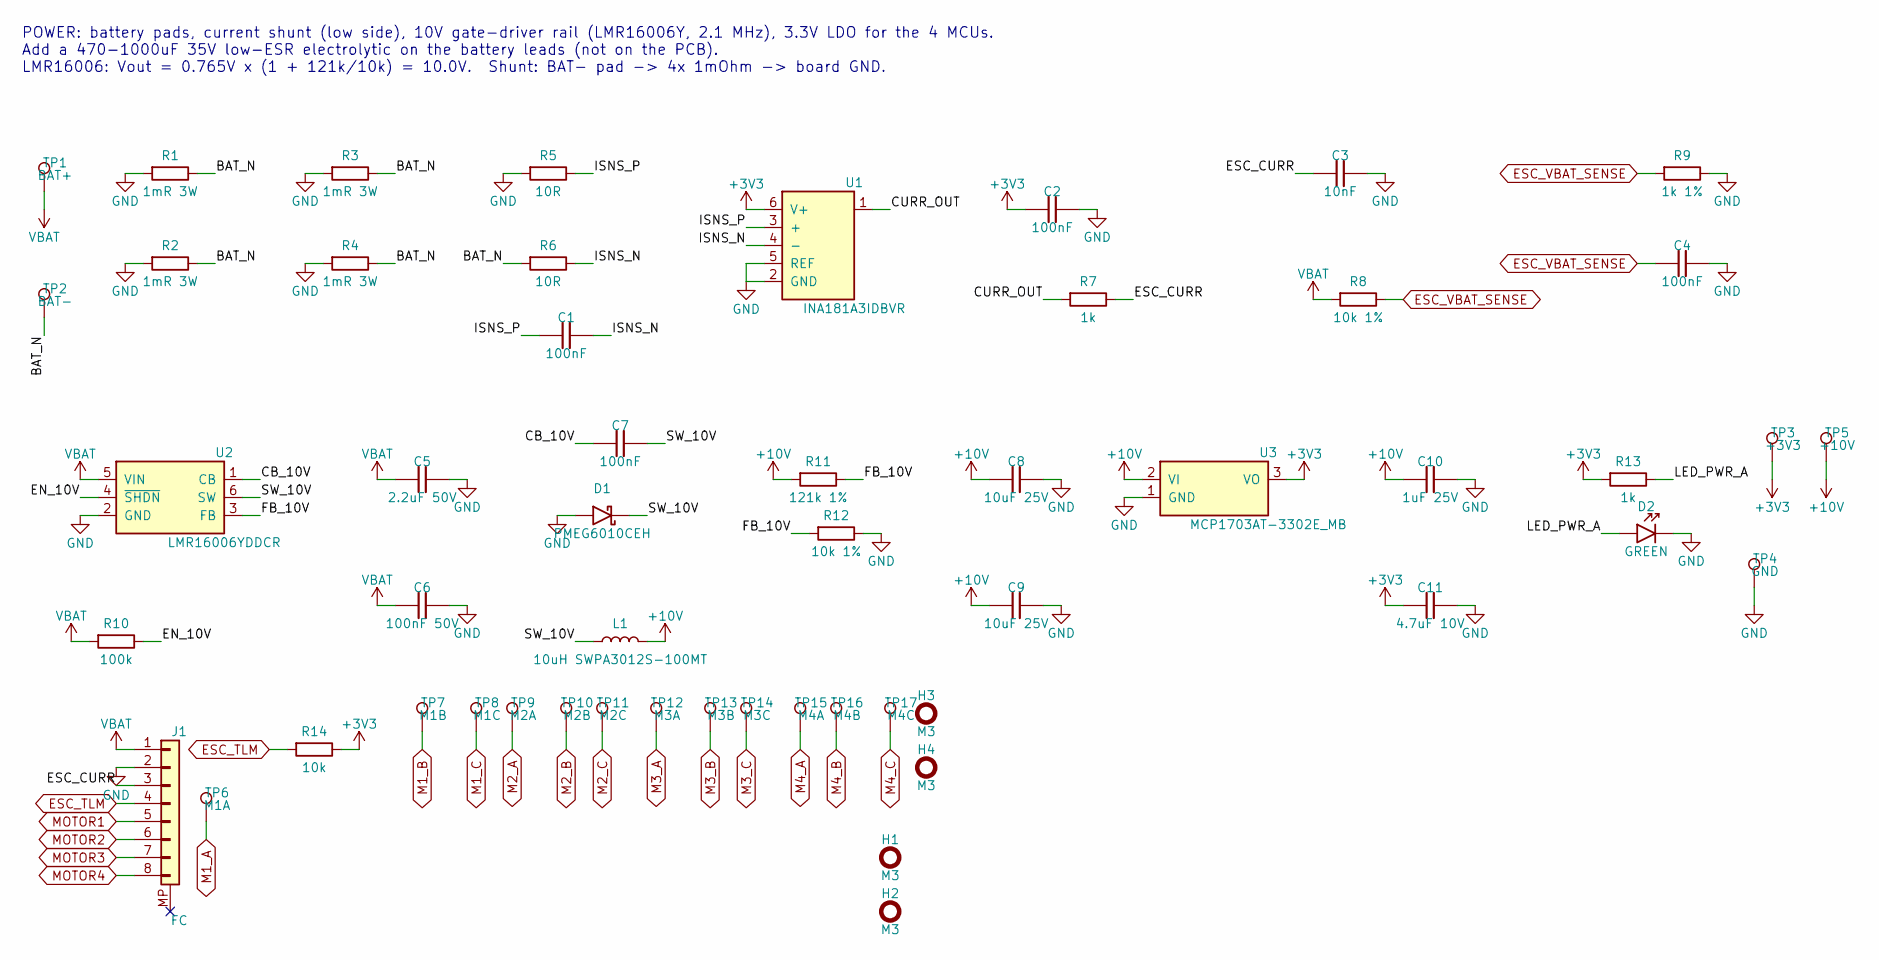
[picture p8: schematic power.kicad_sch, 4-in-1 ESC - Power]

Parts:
C1, C2, C4, C7: 100nF; C_0402_1005Metric
C3: 10nF; C_0402_1005Metric
C5: 2.2uF 50V; C_0805_2012Metric
C6: 100nF 50V; C_0603_1608Metric
C8, C9: 10uF 25V; C_0805_2012Metric
C10: 1uF 25V; C_0603_1608Metric
C11: 4.7uF 10V; C_0603_1608Metric
D1: PMEG6010CEH; D_SOD-123F; MPN PMEG6010CEH,115
D2: GREEN; LED_0603_1608Metric
H1, H2, H3, H4: M3; MountingHole_3.2mm_M3
J1: FC; JST_SH_SM08B-SRSS-TB_1x08-1MP_P1.00mm_Horizontal; MPN SM08B-SRSS-TB(LF)(SN)
L1: 10uH SWPA3012S-100MT; L_Sunlord_SWPA3012S; MPN SWPA3012S100MT
R1, R2, R3, R4: 1mR 3W; R_2512_6332Metric; MPN WSLP2512R0010FEA
R5, R6: 10R; R_0402_1005Metric
R7, R13: 1k; R_0402_1005Metric
R8, R12: 10k 1%; R_0402_1005Metric
R9: 1k 1%; R_0402_1005Metric
R10: 100k; R_0402_1005Metric
R11: 121k 1%; R_0402_1005Metric
R14: 10k; R_0402_1005Metric
TP1: BAT+; SolderPad_5x8mm
TP2: BAT-; SolderPad_5x8mm
TP3: +3V3; TestPoint_Pad_D1.5mm
TP4: GND; TestPoint_Pad_D1.5mm
TP5: +10V; TestPoint_Pad_D1.5mm
TP6: M1A; SolderPad_3x5mm
TP7: M1B; SolderPad_3x5mm
TP8: M1C; SolderPad_3x5mm
TP9: M2A; SolderPad_3x5mm
TP10: M2B; SolderPad_3x5mm
TP11: M2C; SolderPad_3x5mm
TP12: M3A; SolderPad_3x5mm
TP13: M3B; SolderPad_3x5mm
TP14: M3C; SolderPad_3x5mm
TP15: M4A; SolderPad_3x5mm
TP16: M4B; SolderPad_3x5mm
TP17: M4C; SolderPad_3x5mm
U1: INA181A3IDBVR; SOT-23-6; MPN INA181A3IDBVR
U2: LMR16006YDDCR; SOT-23-6; MPN LMR16006YDDCR
U3: MCP1703AT-3302E_MB; SOT-89-3; MPN MCP1703AT-3302E/MB

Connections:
+3V3: C2.1, C11.1, R13.1, R14.2, TP3.1, U1.6 (V+), U3.3 (VO); also elsewhere on the board
+10V: C8.1, C9.1, C10.1, L1.2, R11.1, TP5.1, U3.2 (VI); also elsewhere on the board
/Power/BAT_N: R1.2, R2.2, R3.2, R4.2, R6.1, TP2.1
/Power/CB_10V: C7.1, U2.1 (CB)
/Power/CURR_OUT: R7.1, U1.1
/Power/EN_10V: R10.2, U2.4 (~SHDN)
/Power/ESC_CURR: C3.1, J1.3, R7.2
/Power/FB_10V: R11.2, R12.1, U2.3 (FB)
/Power/ISNS_N: C1.2, R6.2, U1.4 (-)
/Power/ISNS_P: C1.1, R5.2, U1.3 (+)
/Power/LED_PWR_A: D2.2 (A), R13.2
/Power/SW_10V: C7.2, D1.1 (K), L1.1, U2.6 (SW)
ESC_TLM: J1.4, R14.1; also elsewhere on the board
ESC_VBAT_SENSE: C4.1, R8.2, R9.1; also elsewhere on the board
GND: C2.2, C3.2, C4.2, C5.2, C6.2, C8.2, C9.2, C10.2, C11.2, D1.2 (A), D2.1 (K), J1.2, R1.1, R2.1, R3.1, R4.1, R5.1, R9.2, R12.2, TP4.1, U1.2 (GND), U1.5 (REF), U2.2 (GND), U3.1 (GND); also elsewhere on the board
M1_A: TP6.1; also elsewhere on the board
M1_B: TP7.1; also elsewhere on the board
M1_C: TP8.1; also elsewhere on the board
M2_A: TP9.1; also elsewhere on the board
M2_B: TP10.1; also elsewhere on the board
M2_C: TP11.1; also elsewhere on the board
M3_A: TP12.1; also elsewhere on the board
M3_B: TP13.1; also elsewhere on the board
M3_C: TP14.1; also elsewhere on the board
M4_A: TP15.1; also elsewhere on the board
M4_B: TP16.1; also elsewhere on the board
M4_C: TP17.1; also elsewhere on the board
MOTOR1: J1.5; also elsewhere on the board
MOTOR2: J1.6; also elsewhere on the board
MOTOR3: J1.7; also elsewhere on the board
MOTOR4: J1.8; also elsewhere on the board
VBAT: C5.1, C6.1, J1.1, R8.1, R10.1, TP1.1, U2.5 (VIN); also elsewhere on the board

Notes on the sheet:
POWER: battery pads, current shunt (low side), 10V gate-driver rail (LMR16006Y, 2.1 MHz), 3.3V LDO for the 4 MCUs. Add a 470-1000uF 35V low-ESR electrolytic on the battery leads (not on the PCB). LMR16006: Vout = 0.765V x (1 + 121k/10k) = 10.0V. Shunt: BAT- pad -> 4x 1mOhm -> board GND.

Board: 6 copper layers, 233 parts (0 on the bottom side), 160 nets, no tracks yet.

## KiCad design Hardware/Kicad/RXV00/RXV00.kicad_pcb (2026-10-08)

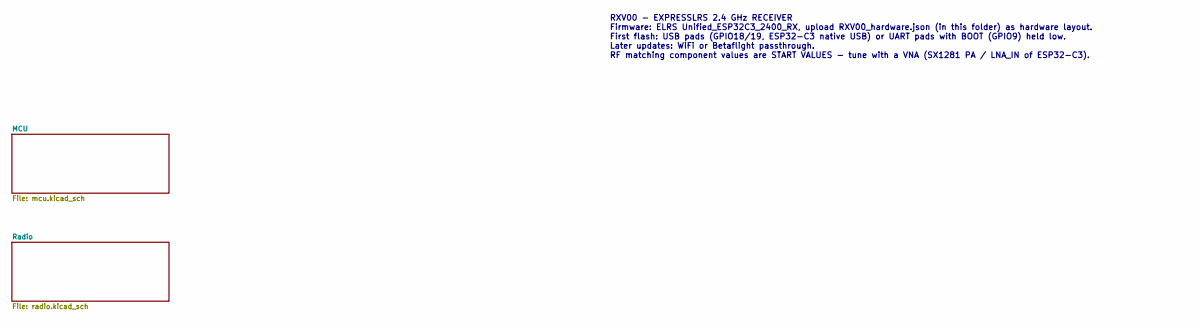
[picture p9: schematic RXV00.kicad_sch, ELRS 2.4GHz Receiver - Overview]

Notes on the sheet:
RXV00 - EXPRESSLRS 2.4 GHz RECEIVER Firmware: ELRS Unified_ESP32C3_2400_RX, upload RXV00_hardware.json (in this folder) as hardware layout. First flash: USB pads (GPIO18/19, ESP32-C3 native USB) or UART pads with BOOT (GPIO9) held low. Later updates: WiFi or Betaflight passthrough. RF matching comp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

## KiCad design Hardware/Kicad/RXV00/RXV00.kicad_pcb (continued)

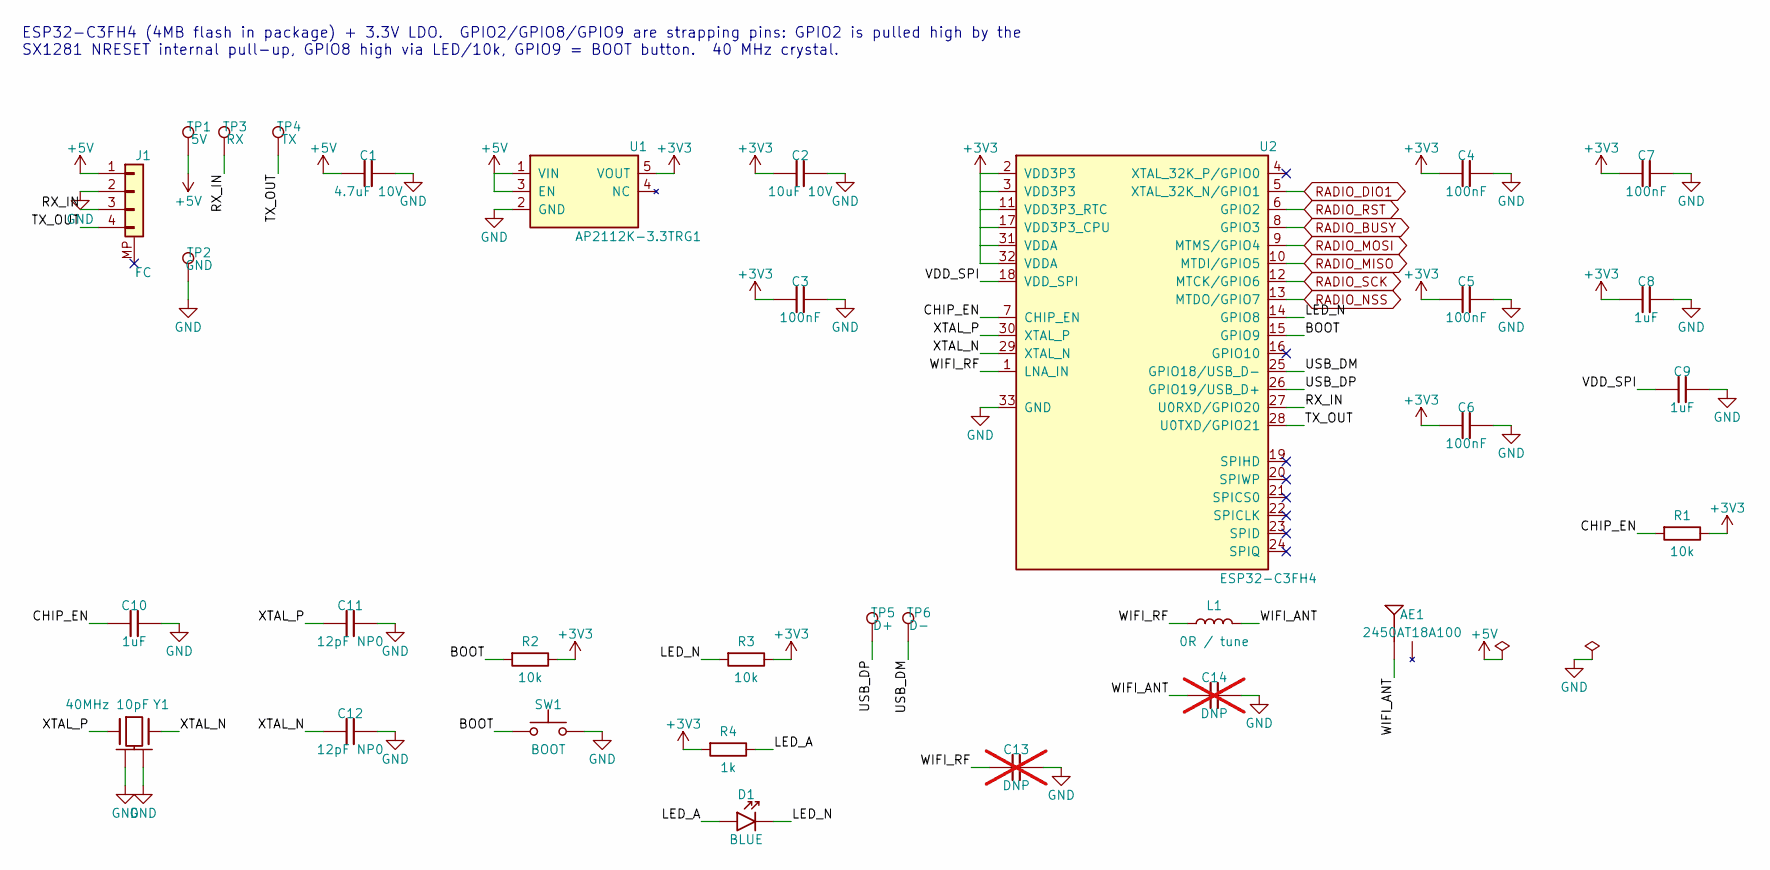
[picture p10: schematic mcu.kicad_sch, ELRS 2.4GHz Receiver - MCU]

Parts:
AE1: 2450AT18A100; Johanson_2450AT18x100; MPN 2450AT18A100E
C1: 4.7uF 10V; C_0603_1608Metric
C2: 10uF 10V; C_0603_1608Metric
C3, C4, C5, C6, C7: 100nF; C_0402_1005Metric
C8, C9, C10: 1uF; C_0402_1005Metric
C11, C12: 12pF NP0; C_0402_1005Metric
C13, C14: DNP; C_0402_1005Metric; not fitted
D1: BLUE; LED_0603_1608Metric
J1: FC; JST_SH_SM04B-SRSS-TB_1x04-1MP_P1.00mm_Horizontal; MPN SM04B-SRSS-TB(LF)(SN)
L1: 0R / tune; L_0402_1005Metric
R1, R2, R3: 10k; R_0402_1005Metric
R4: 1k; R_0402_1005Metric
SW1: BOOT; SW_SPST_B3U-1000P; MPN B3U-1000P
TP1: 5V; TestPoint_Pad_D1.5mm
TP2: GND; TestPoint_Pad_D1.5mm
TP3: RX; TestPoint_Pad_D1.5mm
TP4: TX; TestPoint_Pad_D1.5mm
TP5: D+; TestPoint_Pad_D1.0mm
TP6: D-; TestPoint_Pad_D1.0mm
U1: AP2112K-3.3TRG1; SOT-23-5; MPN AP2112K-3.3TRG1; LCSC C51118
U2: ESP32-C3FH4; QFN-32-1EP_5x5mm_P0.5mm_EP3.7x3.7mm; MPN ESP32-C3FH4
Y1: 40MHz 10pF; Crystal_SMD_2016-4Pin_2.0x1.6mm; MPN X201640MLB4SI

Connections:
+3V3: C2.1, C3.1, C4.1, C5.1, C6.1, C7.1, C8.1, R1.2, R2.2, R3.2, R4.1, U1.5 (VOUT), U2.2 (VDD3P3), U2.3 (VDD3P3), U2.11 (VDD3P3_RTC), U2.17 (VDD3P3_CPU), U2.31 (VDDA), U2.32 (VDDA); also elsewhere on the board
+5V: C1.1, J1.1, TP1.1, U1.1 (VIN), U1.3 (EN)
/MCU/BOOT: R2.1, SW1.1, U2.15 (GPIO9)
/MCU/CHIP_EN: C10.1, R1.1, U2.7 (CHIP_EN)
/MCU/LED_A: D1.2 (A), R4.2
/MCU/LED_N: D1.1 (K), R3.1, U2.14 (GPIO8)
/MCU/RX_IN: J1.3, TP3.1, U2.27 (U0RXD/GPIO20)
/MCU/TX_OUT: J1.4, TP4.1, U2.28 (U0TXD/GPIO21)
/MCU/USB_DM: TP6.1, U2.25 (GPIO18/USB_D-)
/MCU/USB_DP: TP5.1, U2.26 (GPIO19/USB_D+)
/MCU/VDD_SPI: C9.1, U2.18 (VDD_SPI)
/MCU/WIFI_ANT: AE1.1 (FEED), C14.1, L1.2
/MCU/WIFI_RF: C13.1, L1.1, U2.1 (LNA_IN)
/MCU/XTAL_N: C12.1, U2.29 (XTAL_N), Y1.3
/MCU/XTAL_P: C11.1, U2.30 (XTAL_P), Y1.1
GND: C1.2, C2.2, C3.2, C4.2, C5.2, C6.2, C7.2, C8.2, C9.2, C10.2, C11.2, C12.2, C13.2, C14.2, J1.2, SW1.2, TP2.1, U1.2 (GND), U2.33 (GND), Y1.2 (GND), Y1.4 (GND); also elsewhere on the board
RADIO_BUSY: U2.8 (GPIO3); also elsewhere on the board
RADIO_DIO1: U2.5 (XTAL_32K_N/GPIO1); also elsewhere on the board
RADIO_MISO: U2.10 (MTDI/GPIO5); also elsewhere on the board
RADIO_MOSI: U2.9 (MTMS/GPIO4); also elsewhere on the board
RADIO_NSS: U2.13 (MTDO/GPIO7); also elsewhere on the board
RADIO_RST: U2.6 (GPIO2); also elsewhere on the board
RADIO_SCK: U2.12 (MTCK/GPIO6); also elsewhere on the board

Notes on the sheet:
ESP32-C3FH4 (4MB flash in package) + 3.3V LDO. GPIO2/GPIO8/GPIO9 are strapping pins: GPIO2 is pulled high by the SX1281 NRESET internal pull-up, GPIO8 high via LED/10k, GPIO9 = BOOT button. 40 MHz crystal.

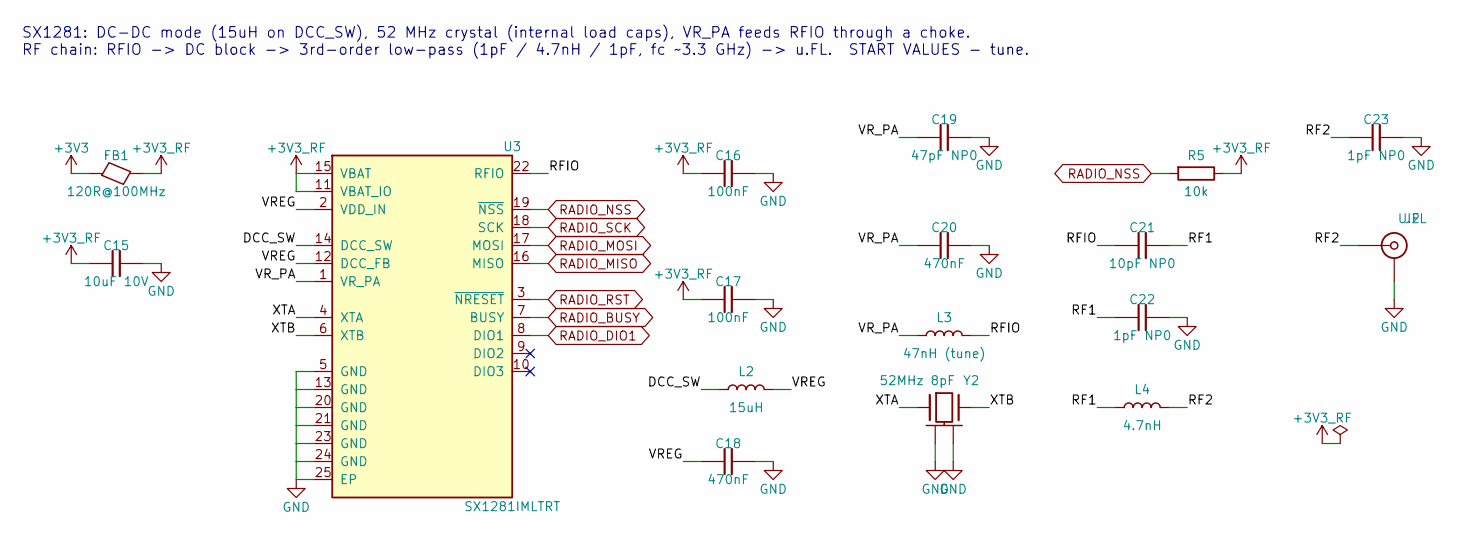
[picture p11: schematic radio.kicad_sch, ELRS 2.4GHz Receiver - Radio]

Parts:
C15: 10uF 10V; C_0603_1608Metric
C16, C17: 100nF; C_0402_1005Metric
C18, C20: 470nF; C_0402_1005Metric
C19: 47pF NP0; C_0402_1005Metric
C21: 10pF NP0; C_0402_1005Metric
C22, C23: 1pF NP0; C_0402_1005Metric
FB1: 120R@100MHz; L_0402_1005Metric; MPN BLM15PX121SN1D
J2: U.FL; U.FL_Hirose_U.FL-R-SMT-1_Vertical; MPN U.FL-R-SMT-1(10)
L2: 15uH; L_0805_2012Metric; MPN LQM21PN150MC0
L3: 47nH (tune); L_0402_1005Metric; MPN LQW15AN47NJ00
L4: 4.7nH; L_0402_1005Metric; MPN LQP15MN4N7B02
R5: 10k; R_0402_1005Metric
U3: SX1281IMLTRT; QFN-24-1EP_4x4mm_P0.5mm_EP2.6x2.6mm; MPN SX1281IMLTRT
Y2: 52MHz 8pF; Crystal_SMD_2016-4Pin_2.0x1.6mm; MPN X201652MOB4SI

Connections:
+3V3: FB1.1; also elsewhere on the board
+3V3_RF: C15.1, C16.1, C17.1, FB1.2, R5.2, U3.11 (VBAT_IO), U3.15 (VBAT)
/Radio/DCC_SW: L2.1, U3.14 (DCC_SW)
/Radio/RF1: C21.2, C22.1, L4.1
/Radio/RF2: C23.1, J2.1 (In), L4.2
/Radio/RFIO: C21.1, L3.2, U3.22 (RFIO)
/Radio/VREG: C18.1, L2.2, U3.2 (VDD_IN), U3.12 (DCC_FB)
/Radio/VR_PA: C19.1, C20.1, L3.1, U3.1 (VR_PA)
/Radio/XTA: U3.4 (XTA), Y2.1
/Radio/XTB: U3.6 (XTB), Y2.3
GND: C15.2, C16.2, C17.2, C18.2, C19.2, C20.2, C22.2, C23.2, J2.2 (Ext), U3.5 (GND), U3.13 (GND), U3.20 (GND), U3.21 (GND), U3.23 (GND), U3.24 (GND), U3.25 (EP), Y2.2 (GND), Y2.4 (GND); also elsewhere on the board
RADIO_BUSY: U3.7 (BUSY); also elsewhere on the board
RADIO_DIO1: U3.8 (DIO1); also elsewhere on the board
RADIO_MISO: U3.16 (MISO); also elsewhere on the board
RADIO_MOSI: U3.17 (MOSI); also elsewhere on the board
RADIO_NSS: R5.1, U3.19 (~NSS); also elsewhere on the board
RADIO_RST: U3.3 (~NRESET); also elsewhere on the board
RADIO_SCK: U3.18 (SCK); also elsewhere on the board

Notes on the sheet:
SX1281: DC-DC mode (15uH on DCC_SW), 52 MHz crystal (internal load caps), VR_PA feeds RFIO through a choke. RF chain: RFIO -> DC block -> 3rd-order low-pass (1pF / 4.7nH / 1pF, fc ~3.3 GHz) -> u.FL. START VALUES - tune.

Board: 4 copper layers, 49 parts (0 on the bottom side), 32 nets, no tracks yet.

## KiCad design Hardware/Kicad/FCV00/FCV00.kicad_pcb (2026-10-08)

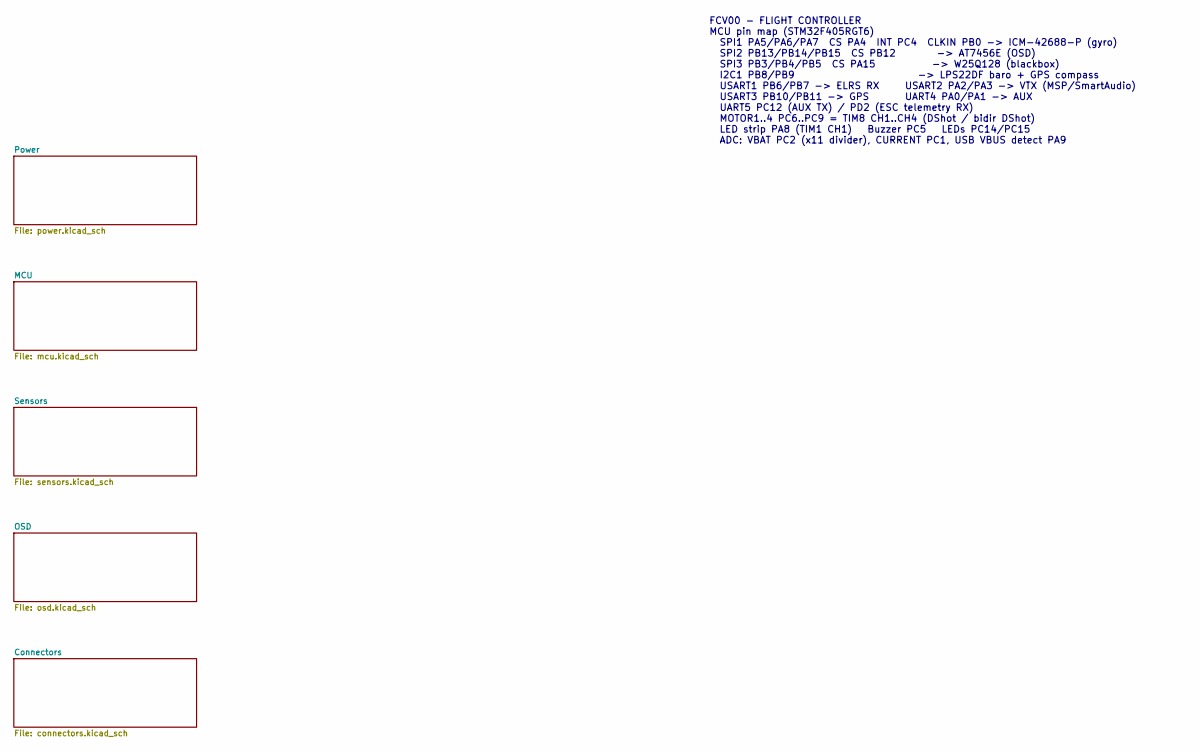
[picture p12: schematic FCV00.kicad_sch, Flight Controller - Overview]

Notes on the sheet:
FCV00 - FLIGHT CONTROLLER MCU pin map (STM32F405RGT6) SPI1 PA5/PA6/PA7 CS PA4 INT PC4 CLKIN PB0 -> ICM-42688-P (gyro) SPI2 PB13/PB14/PB15 CS PB12 -> AT7456E (OSD) SPI3 PB3/PB4/PB5 CS PA15 -> W25Q128 (blackbox) I2C1 PB8/PB9 -> LPS22DF baro + GPS compass USART1 PB6/PB7 -> ELRS RX USART2 PA2/PA3 -> VT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

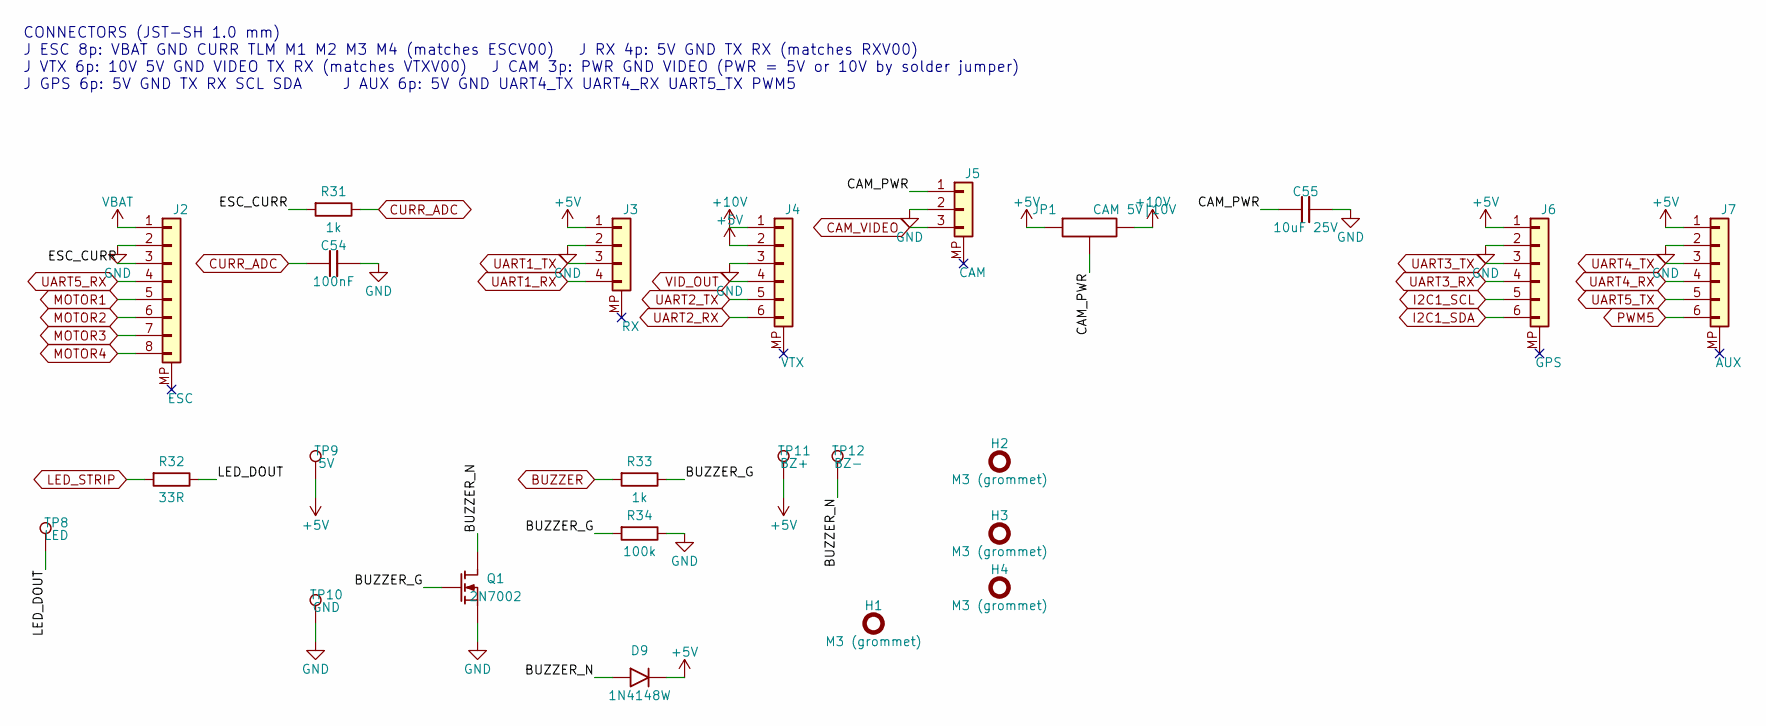
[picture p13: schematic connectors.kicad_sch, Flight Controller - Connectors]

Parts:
C54: 100nF; C_0402_1005Metric
C55: 10uF 25V; C_0805_2012Metric
D9: 1N4148W; D_SOD-123; MPN 1N4148W
H1, H2, H3, H4: M3 (grommet); MountingHole_4mm
J2: ESC; JST_SH_SM08B-SRSS-TB_1x08-1MP_P1.00mm_Horizontal; MPN SM08B-SRSS-TB(LF)(SN)
J3: RX; JST_SH_SM04B-SRSS-TB_1x04-1MP_P1.00mm_Horizontal; MPN SM04B-SRSS-TB(LF)(SN)
J4: VTX; JST_SH_SM06B-SRSS-TB_1x06-1MP_P1.00mm_Horizontal; MPN SM06B-SRSS-TB(LF)(SN)
J5: CAM; JST_SH_SM03B-SRSS-TB_1x03-1MP_P1.00mm_Horizontal; MPN SM03B-SRSS-TB(LF)(SN)
J6: GPS; JST_SH_SM06B-SRSS-TB_1x06-1MP_P1.00mm_Horizontal; MPN SM06B-SRSS-TB(LF)(SN)
J7: AUX; JST_SH_SM06B-SRSS-TB_1x06-1MP_P1.00mm_Horizontal; MPN SM06B-SRSS-TB(LF)(SN)
JP1: CAM 5V|10V; SolderJumper-3_P1.3mm_Open_RoundedPad1.0x1.5mm
Q1: 2N7002; SOT-23; MPN 2N7002,215; LCSC C8545
R31, R33: 1k; R_0402_1005Metric
R32: 33R; R_0402_1005Metric
R34: 100k; R_0402_1005Metric
TP8: LED; TestPoint_Pad_2.0x2.0mm
TP9: 5V; TestPoint_Pad_2.0x2.0mm
TP10: GND; TestPoint_Pad_2.0x2.0mm
TP11: BZ+; TestPoint_Pad_2.0x2.0mm
TP12: BZ-; TestPoint_Pad_2.0x2.0mm

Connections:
+5V: D9.1 (K), J3.1, J4.2, J6.1, J7.1, JP1.1 (A), TP9.1, TP11.1; also elsewhere on the board
+10V: J4.1, JP1.3 (B); also elsewhere on the board
/Connectors/BUZZER_G: Q1.1 (G), R33.2, R34.1
/Connectors/BUZZER_N: D9.2 (A), Q1.3 (D), TP12.1
/Connectors/CAM_PWR: C55.1, J5.1, JP1.2 (C)
/Connectors/ESC_CURR: J2.3, R31.1
/Connectors/LED_DOUT: R32.2, TP8.1
BUZZER: R33.1; also elsewhere on the board
CAM_VIDEO: J5.3; also elsewhere on the board
CURR_ADC: C54.1, R31.2; also elsewhere on the board
GND: C54.2, C55.2, J2.2, J3.2, J4.3, J5.2, J6.2, J7.2, Q1.2 (S), R34.2, TP10.1; also elsewhere on the board
I2C1_SCL: J6.5; also elsewhere on the board
I2C1_SDA: J6.6; also elsewhere on the board
LED_STRIP: R32.1; also elsewhere on the board
MOTOR1: J2.5; also elsewhere on the board
MOTOR2: J2.6; also elsewhere on the board
MOTOR3: J2.7; also elsewhere on the board
MOTOR4: J2.8; also elsewhere on the board
PWM5: J7.6; also elsewhere on the board
UART1_RX: J3.4; also elsewhere on the board
UART1_TX: J3.3; also elsewhere on the board
UART2_RX: J4.6; also elsewhere on the board
UART2_TX: J4.5; also elsewhere on the board
UART3_RX: J6.4; also elsewhere on the board
UART3_TX: J6.3; also elsewhere on the board
UART4_RX: J7.4; also elsewhere on the board
UART4_TX: J7.3; also elsewhere on the board
UART5_RX: J2.4; also elsewhere on the board
UART5_TX: J7.5; also elsewhere on the board
VBAT: J2.1; also elsewhere on the board
VID_OUT: J4.4; also elsewhere on the board

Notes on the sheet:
CONNECTORS (JST-SH 1.0 mm) J ESC 8p: VBAT GND CURR TLM M1 M2 M3 M4 (matches ESCV00) J RX 4p: 5V GND TX RX (matches RXV00) J VTX 6p: 10V 5V GND VIDEO TX RX (matches VTXV00) J CAM 3p: PWR GND VIDEO (PWR = 5V or 10V by solder jumper) J GPS 6p: 5V GND TX RX SCL SDA J AUX 6p: 5V GND UART4_TX UART4_RX UA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

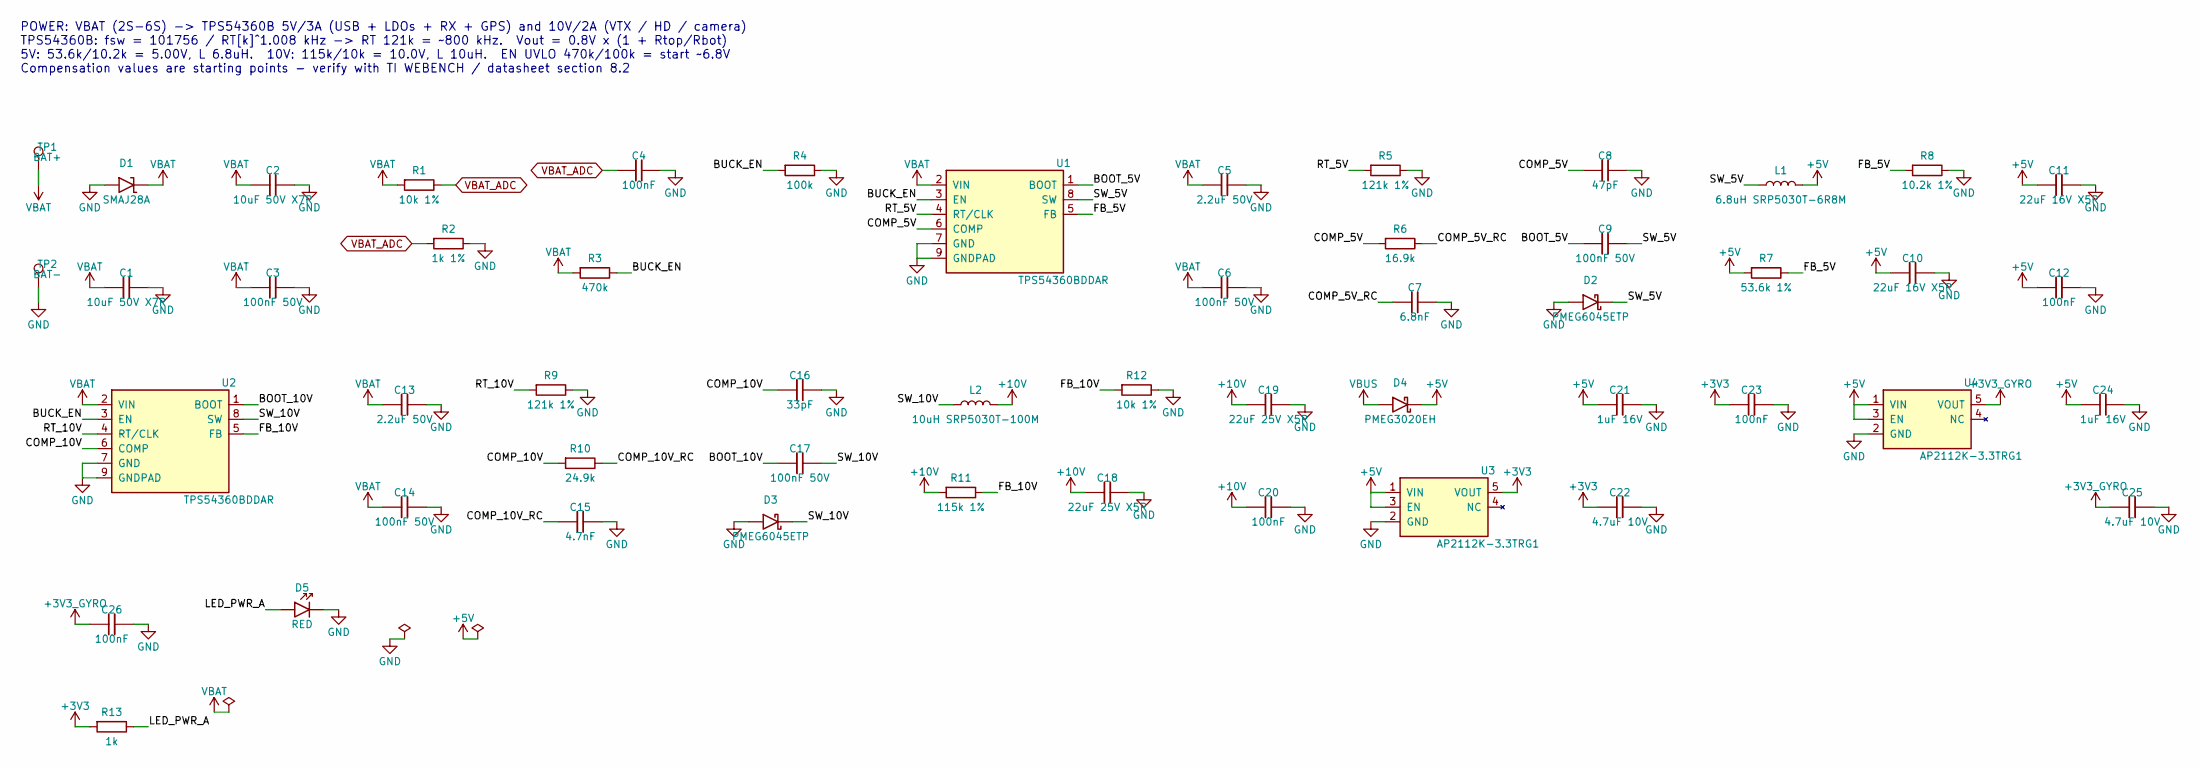
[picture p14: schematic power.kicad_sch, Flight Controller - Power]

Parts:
C1, C2: 10uF 50V X7R; C_1206_3216Metric
C3, C6, C9, C14, C17: 100nF 50V; C_0603_1608Metric
C4, C12, C20, C23, C26: 100nF; C_0402_1005Metric
C5, C13: 2.2uF 50V; C_0805_2012Metric
C7: 6.8nF; C_0402_1005Metric
C8: 47pF; C_0402_1005Metric
C10, C11: 22uF 16V X5R; C_0805_2012Metric
C15: 4.7nF; C_0402_1005Metric
C16: 33pF; C_0402_1005Metric
C18, C19: 22uF 25V X5R; C_1206_3216Metric
C21, C24: 1uF 16V; C_0402_1005Metric
C22, C25: 4.7uF 10V; C_0603_1608Metric
D1: SMAJ28A; D_SMA; MPN SMAJ28A
D2, D3: PMEG6045ETP; D_SOD-128; MPN PMEG6045ETPX
D4: PMEG3020EH; D_SOD-123F; MPN PMEG3020EH,115
D5: RED; LED_0603_1608Metric; MPN KT-0603R
L1: 6.8uH SRP5030T-6R8M; L_Bourns_SRP5030T; MPN SRP5030T-6R8M
L2: 10uH SRP5030T-100M; L_Bourns_SRP5030T; MPN SRP5030T-100M
R1, R12: 10k 1%; R_0402_1005Metric
R2: 1k 1%; R_0402_1005Metric
R3: 470k; R_0402_1005Metric
R4: 100k; R_0402_1005Metric
R5, R9: 121k 1%; R_0402_1005Metric
R6: 16.9k; R_0402_1005Metric
R7: 53.6k 1%; R_0402_1005Metric
R8: 10.2k 1%; R_0402_1005Metric
R10: 24.9k; R_0402_1005Metric
R11: 115k 1%; R_0402_1005Metric
R13: 1k; R_0402_1005Metric
TP1: BAT+; SolderPad_3x5mm
TP2: BAT-; SolderPad_3x5mm
U1, U2: TPS54360BDDAR; TI_SO-PowerPAD-8_ThermalVias; MPN TPS54360BDDAR
U3, U4: AP2112K-3.3TRG1; SOT-23-5; MPN AP2112K-3.3TRG1; LCSC C51118

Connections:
+3V3: C22.1, C23.1, R13.1, U3.5 (VOUT); also elsewhere on the board
+3V3_GYRO: C25.1, C26.1, U4.5 (VOUT); also elsewhere on the board
+5V: C10.1, C11.1, C12.1, C21.1, C24.1, D4.1 (K), L1.2, R7.1, U3.1 (VIN), U3.3 (EN), U4.1 (VIN), U4.3 (EN); also elsewhere on the board
+10V: C18.1, C19.1, C20.1, L2.2, R11.1; also elsewhere on the board
/Power/BOOT_5V: C9.1, U1.1 (BOOT)
/Power/BOOT_10V: C17.1, U2.1 (BOOT)
/Power/BUCK_EN: R3.2, R4.1, U1.3 (EN), U2.3 (EN)
/Power/COMP_5V: C8.1, R6.1, U1.6 (COMP)
/Power/COMP_5V_RC: C7.1, R6.2
/Power/COMP_10V: C16.1, R10.1, U2.6 (COMP)
/Power/COMP_10V_RC: C15.1, R10.2
/Power/FB_5V: R7.2, R8.1, U1.5 (FB)
/Power/FB_10V: R11.2, R12.1, U2.5 (FB)
/Power/LED_PWR_A: D5.2 (A), R13.2
/Power/RT_5V: R5.1, U1.4 (RT/CLK)
/Power/RT_10V: R9.1, U2.4 (RT/CLK)
/Power/SW_5V: C9.2, D2.1 (K), L1.1, U1.8 (SW)
/Power/SW_10V: C17.2, D3.1 (K), L2.1, U2.8 (SW)
GND: C1.2, C2.2, C3.2, C4.2, C5.2, C6.2, C7.2, C8.2, C10.2, C11.2, C12.2, C13.2, C14.2, C15.2, C16.2, C18.2, C19.2, C20.2, C21.2, C22.2, C23.2, C24.2, C25.2, C26.2, D1.2 (A), D2.2 (A), D3.2 (A), D5.1 (K), R2.2, R4.2, R5.2, R8.2, R9.2, R12.2, TP2.1, U1.7 (GND), U1.9 (GNDPAD), U2.7 (GND), U2.9 (GNDPAD), U3.2 (GND), U4.2 (GND); also elsewhere on the board
VBAT: C1.1, C2.1, C3.1, C5.1, C6.1, C13.1, C14.1, D1.1 (K), R1.1, R3.1, TP1.1, U1.2 (VIN), U2.2 (VIN); also elsewhere on the board
VBAT_ADC: C4.1, R1.2, R2.1; also elsewhere on the board
VBUS: D4.2 (A); also elsewhere on the board

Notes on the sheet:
POWER: VBAT (2S-6S) -> TPS54360B 5V/3A (USB + LDOs + RX + GPS) and 10V/2A (VTX / HD / camera) TPS54360B: fsw = 101756 / RT[k]^1.008 kHz -> RT 121k = ~800 kHz. Vout = 0.8V x (1 + Rtop/Rbot) 5V: 53.6k/10.2k = 5.00V, L 6.8uH. 10V: 115k/10k = 10.0V, L 10uH. EN UVLO 470k/100k = start ~6.8V Compensation 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


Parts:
C27, C28, C29, C30, C31, C34, C39: 100nF; C_0402_1005Metric
C32: 4.7uF 10V; C_0603_1608Metric
C33: 1uF; C_0402_1005Metric
C35, C36: 2.2uF; C_0402_1005Metric
C37, C38: 18pF NP0; C_0402_1005Metric
C40: 1uF 16V; C_0402_1005Metric
D6: BLUE; LED_0603_1608Metric
D7: GREEN; LED_0603_1608Metric
D8: USBLC6-2SC6; SOT-23-6; MPN USBLC6-2SC6; LCSC C7519
FB1: 600R@100MHz; L_0402_1005Metric; MPN BLM15AG601SN1D
J1: USB_C_GCT_USB4105-GF-A; USB_C_Receptacle_GCT_USB4105-xx-A_16P_TopMnt_Horizontal; MPN USB4105-GF-A
R14, R15, R20: 10k; R_0402_1005Metric
R16, R17: 1k; R_0402_1005Metric
R18, R19: 5.1k; R_0402_1005Metric
R21: 20k; R_0402_1005Metric
SW1: BOOT; SW_SPST_B3U-1000P; MPN B3U-1000P
TP3: SWDIO; TestPoint_Pad_D1.0mm
TP4: SWCLK; TestPoint_Pad_D1.0mm
TP5: NRST; TestPoint_Pad_D1.0mm
TP6: +3V3; TestPoint_Pad_D1.0mm
TP7: GND; TestPoint_Pad_D1.0mm
U5: STM32F405RGT6; LQFP-64_10x10mm_P0.5mm; MPN STM32F405RGT6; LCSC C15742
Y1: 8MHz 12pF; Crystal_SMD_3225-4Pin_3.2x2.5mm; MPN X322508MLB4SI

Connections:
+3V3: C27.1, C28.1, C29.1, C30.1, C31.1, C32.1, FB1.1, R16.1, R17.1, SW1.1, TP6.1, U5.1 (VBAT), U5.19 (VDD), U5.32 (VDD), U5.48 (VDD), U5.64 (VDD); also elsewhere on the board
/MCU/BOOT0: R14.1, SW1.2, U5.60 (BOOT0)
/MCU/BOOT1: R15.1, U5.28 (PB2)
/MCU/LED0: D6.1 (K), U5.3 (PC14)
/MCU/LED0_A: D6.2 (A), R16.2
/MCU/LED1: D7.1 (K), U5.4 (PC15)
/MCU/LED1_A: D7.2 (A), R17.2
/MCU/NRST: C39.1, TP5.1, U5.7 (NRST)
/MCU/OSC_IN: C37.1, U5.5 (PH0), Y1.1
/MCU/OSC_OUT: C38.1, U5.6 (PH1), Y1.3
/MCU/SWCLK: TP4.1, U5.49 (PA14)
/MCU/SWDIO: TP3.1, U5.46 (PA13)
/MCU/USB_CC1: J1.A5 (CC1), R18.1
/MCU/USB_CC2: J1.B5 (CC2), R19.1
/MCU/USB_DM: D8.3 (I/O2), D8.4 (I/O2), J1.A7 (D-), J1.B7 (D-), U5.44 (PA11)
/MCU/USB_DP: D8.1 (I/O1), D8.6 (I/O1), J1.A6 (D+), J1.B6 (D+), U5.45 (PA12)
/MCU/USB_VBUS_DET: R20.2, R21.1, U5.42 (PA9)
/MCU/VCAP1: C35.1, U5.31 (VCAP_1)
/MCU/VCAP2: C36.1, U5.47 (VCAP_2)
/MCU/VDDA: C33.1, C34.1, FB1.2, U5.13 (VDDA)
BUZZER: U5.25 (PC5); also elsewhere on the board
CURR_ADC: U5.9 (PC1); also elsewhere on the board
FLASH_CS: U5.50 (PA15); also elsewhere on the board
GND: C27.2, C28.2, C29.2, C30.2, C31.2, C32.2, C33.2, C34.2, C35.2, C36.2, C37.2, C38.2, C39.2, C40.2, D8.2 (GND), J1.A1 (GND), J1.A12 (GND), J1.B1 (GND), J1.B12 (GND), J1.S1 (SHIELD), R14.2, R15.2, R18.2, R19.2, R21.2, TP7.1, U5.12 (VSSA), U5.18 (VSS), U5.63 (VSS), Y1.2 (GND), Y1.4 (GND); also elsewhere on the board
GYRO_CLKIN: U5.26 (PB0); also elsewhere on the board
GYRO_CS: U5.20 (PA4); also elsewhere on the board
GYRO_INT1: U5.24 (PC4); also elsewhere on the board
I2C1_SCL: U5.61 (PB8); also elsewhere on the board
I2C1_SDA: U5.62 (PB9); also elsewhere on the board
LED_STRIP: U5.41 (PA8); also elsewhere on the board
MOTOR1: U5.37 (PC6); also elsewhere on the board
MOTOR2: U5.38 (PC7); also elsewhere on the board
MOTOR3: U5.39 (PC8); also elsewhere on the board
MOTOR4: U5.40 (PC9); also elsewhere on the board
OSD_CS: U5.33 (PB12); also elsewhere on the board
PWM5: U5.27 (PB1); also elsewhere on the board
SPI1_MISO: U5.22 (PA6); also elsewhere on the board
SPI1_MOSI: U5.23 (PA7); also elsewhere on the board
SPI1_SCK: U5.21 (PA5); also elsewhere on the board
SPI2_MISO: U5.35 (PB14); also elsewhere on the board
SPI2_MOSI: U5.36 (PB15); also elsewhere on the board
SPI2_SCK: U5.34 (PB13); also elsewhere on the board
SPI3_MISO: U5.56 (PB4); also elsewhere on the board
SPI3_MOSI: U5.57 (PB5); also elsewhere on the board
SPI3_SCK: U5.55 (PB3); also elsewhere on the board
UART1_RX: U5.59 (PB7); also elsewhere on the board
UART1_TX: U5.58 (PB6); also elsewhere on the board
UART2_RX: U5.17 (PA3); also elsewhere on the board
UART2_TX: U5.16 (PA2); also elsewhere on the board
UART3_RX: U5.30 (PB11); also elsewhere on the board
UART3_TX: U5.29 (PB10); also elsewhere on the board
UART4_RX: U5.15 (PA1); also elsewhere on the board
UART4_TX: U5.14 (PA0); also elsewhere on the board
UART5_RX: U5.54 (PD2); also elsewhere on the board
UART5_TX: U5.53 (PC12); also elsewhere on the board
VBAT_ADC: U5.10 (PC2); also elsewhere on the board
VBUS: C40.1, D8.5 (VBUS), J1.A4 (VBUS), J1.A9 (VBUS), J1.B4 (VBUS), J1.B9 (VBUS), R20.1; also elsewhere on the board

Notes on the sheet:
MCU: STM32F405RGT6 168 MHz, HSE 8 MHz. BOOT0 button = DFU over USB-C. SWD on test pads.


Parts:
C41, C43, C44, C45: 100nF; C_0402_1005Metric
C42: 1uF; C_0402_1005Metric
R22, R25, R26, R27: 10k; R_0402_1005Metric
R23, R24: 2.2k; R_0402_1005Metric
U6: ICM-42688-P; Bosch_LGA-14_3x2.5mm_P0.5mm; MPN ICM-42688-P
U7: LPS22DF; ST_HLGA-10_2x2mm_P0.5mm_LayoutBorder3x2y; MPN LPS22DFTR
U8: W25Q128JVSIQ; SOIC-8_5.23x5.23mm_P1.27mm; MPN W25Q128JVSIQ; LCSC C97521

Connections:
+3V3: C44.1, C45.1, R23.2, R24.2, R25.2, R26.2, R27.2, U7.1 (Vdd_IO), U7.6 (~CS), U7.10 (VDD), U8.8 (VCC); also elsewhere on the board
+3V3_GYRO: C41.1, C42.1, C43.1, R22.2, U6.5 (VDDIO), U6.8 (VDD); also elsewhere on the board
/Sensors/FLASH_HOLD: R27.1, U8.7 (IO3)
/Sensors/FLASH_WP: R26.1, U8.3 (IO2)
FLASH_CS: R25.1, U8.1 (~CS); also elsewhere on the board
GND: C41.2, C42.2, C43.2, C44.2, C45.2, U6.6 (GND), U6.7 (GND), U7.3 (GND), U7.5 (SA0), U7.8 (GND_IO), U7.9 (GND), U8.4 (GND); also elsewhere on the board
GYRO_CLKIN: U6.9 (INT2/FSYNC/CLKIN); also elsewhere on the board
GYRO_CS: R22.1, U6.12 (AP_CS); also elsewhere on the board
GYRO_INT1: U6.4 (INT1/INT); also elsewhere on the board
I2C1_SCL: R23.1, U7.2 (SCL); also elsewhere on the board
I2C1_SDA: R24.1, U7.4 (SDA); also elsewhere on the board
SPI1_MISO: U6.1 (AP_SDO/AP_AD0); also elsewhere on the board
SPI1_MOSI: U6.14 (AP_SDA/AP_SDIO/AP_SDI); also elsewhere on the board
SPI1_SCK: U6.13 (AP_SCL/AP_SCLK); also elsewhere on the board
SPI3_MISO: U8.2 (DO(IO1)); also elsewhere on the board
SPI3_MOSI: U8.5 (DI(IO0)); also elsewhere on the board
SPI3_SCK: U8.6 (CLK); also elsewhere on the board

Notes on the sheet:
SENSORS: ICM-42688-P on dedicated SPI1 + own LDO (+3V3_GYRO). INT2/CLKIN driven by PB0 (TIM3) for external 32 kHz clock. LPS22DF baro on I2C1 (addr 0x5C, SA0=0). W25Q128JV blackbox flash on SPI3.


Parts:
C46: 10uF 10V; C_0603_1608Metric
C47, C48, C49, C50, C53: 100nF; C_0402_1005Metric
C51, C52: 18pF NP0; C_0402_1005Metric
FB2: 600R@100MHz; L_0603_1608Metric; MPN BLM18AG601SN1D
R28: 10k; R_0402_1005Metric
R29: 75R 1%; R_0402_1005Metric
R30: 0R; R_0402_1005Metric; not fitted
U9: AT7456E; HTSSOP-28-1EP_4.4x9.7mm_P0.65mm_EP2.85x5.4mm; MPN AT7456E; LCSC C82351
Y2: 27MHz 12pF; Crystal_SMD_3225-4Pin_3.2x2.5mm; MPN X322527MOB4SI

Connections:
+3V3: FB2.1; also elsewhere on the board
+3V3_OSD: C46.1, C47.1, C48.1, C49.1, FB2.2, R28.2, U9.3 (DVDD), U9.21 (AVDD), U9.24 (PVDD)
/OSD/OSD_RST: C50.1, R28.1, U9.19 (~RESET)
/OSD/OSD_VIN: C53.2, U9.22 (VIN)
/OSD/OSD_XI: C51.1, U9.5 (CLKIN), Y2.1
/OSD/OSD_XO: C52.1, U9.6 (XFB), Y2.3
CAM_VIDEO: C53.1, R29.1, R30.1; also elsewhere on the board
GND: C46.2, C47.2, C48.2, C49.2, C50.2, C51.2, C52.2, R29.2, U9.4 (DGND), U9.20 (AGND), U9.23 (PGND), U9.29 (EP), Y2.2 (GND), Y2.4 (GND); also elsewhere on the board
OSD_CS: U9.8 (~CS); also elsewhere on the board
SPI2_MISO: U9.11 (SDOUT); also elsewhere on the board
SPI2_MOSI: U9.9 (SDIN); also elsewhere on the board
SPI2_SCK: U9.10 (SCLK); also elsewhere on the board
VID_OUT: R30.2, U9.25 (SAG), U9.26 (VOUT); also elsewhere on the board

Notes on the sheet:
OSD: AT7456E (MAX7456 compatible) on SPI2, supplied at 3.3V (spec 3.15-5.25V) so SPI levels match the MCU. Camera video: 75R termination + 100nF AC coupling into VIN. VOUT drives the VTX input (75R) directly; SAG tied to VOUT. R (DNP) = OSD bypass for debugging.

Board: 4 copper layers, 139 parts (0 on the bottom side), 89 nets, no tracks yet.

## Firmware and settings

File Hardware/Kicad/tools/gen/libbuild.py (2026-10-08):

"""Build the drone part libraries in the eXxx folder layout:

  KiCad_Libs_ToAdd/<eLib>/
      datasheet/            datasheets (PDF when redistributable here, otherwise links in README.md)
      <eLib>.3dshapes/      STEP models (from the official KiCad 3D library)
      <eLib>.pretty/        footprints (from the official KiCad footprint library)
      <eLib>.kicad_sym      symbols
      .gitignore
"""
import os
import re
import shutil
import subprocess
import tempfile
import sys

import parts as P
from symlib import ic_symbol, small_symbol, conn_symbol, power_symbol

ROOT = os.path.abspath(os.path.join(os.path.dirname(__file__), "..", "..", "KiCad_Libs_ToAdd"))
KICAD_FP = "/usr/share/kicad/footprints"
MODEL_CACHE = os.path.join(tempfile.gettempdir(), "kicad_models")
P3D_GIT = "/home/user/kicadlib/p3d"
MODEL_URL = "https://raw.githubusercontent.com/KiCad/kicad-packages3D/master/"
OPENVTX_DOCS = "/home/user/openvtx/openvtx/docs"

POWER_NETS = ["GND", "+3V3", "+3V3_GYRO", "+3V3_OSD", "+5V", "+10V", "VBAT", "VBUS", "+5V_PA", "+3V3_RF"]

SYMBOLS = {}  # lib_id -> dict(text, geo, bbox, types)


def build_symbols():
    for part in P.PARTS.values():
        fp = part.fp_id or P.PartDefaults.get(part.name, "")
        if part.kind == "ic":
            text, geo, bbox = ic_symbol(part.name, part.pins, part.left, part.right, part.ref, fp, part.fields)
            types = {n: t for n, _, t in part.pins}
            names = {n: nm for n, nm, _ in part.pins}
        elif part.kind == "conn":
            text, geo, bbox = conn_symbol(part.name, part.npins, part.ref, fp, part.fields)
            types = {k: "passive" for k in geo}
            names = {k: k for k in geo}
        else:
            text, geo, bbox = small_symbol(part.name, part.kind, part.ref, fp, part.fields)
            types, names = {}, {}
            for m in re.finditer(r'\(pin (\w+) line .*?\(name "([^"]*)".*?\(number "([^"]+)"', text, re.S):
                types[m.group(3)] = m.group(1)
                names[m.group(3)] = m.group(2) if m.group(2) not in ("~", m.group(3)) else m.group(3)
        SYMBOLS[part.lib_id] = dict(text=text, geo=geo, bbox=bbox, types=types, names=names, part=part)
    for net in POWER_NETS + ["PWR_FLAG"]:
        kind = "flag" if net == "PWR_FLAG" else P.power_kind(net)
        SYMBOLS[f"ePowerSym:{net}"] = dict(text=power_symbol(net, kind), geo={"1": (0, 0, 0)}, bbox=(-1.27, -2.54, 1.27, 2.54),
                                            types={"1": "power_out" if kind == "flag" else "power_in"},
                                            names={"1": net}, part=None, power=kind)


def write_symbol_libs():
    libs = {}
    for lib_id, s in SYMBOLS.items():
        lib = lib_id.split(":")[0]
        libs.setdefault(lib, []).append(s["text"])
    for lib, texts in libs.items():
        d = os.path.join(ROOT, lib)
        os.makedirs(d, exist_ok=True)
        with open(os.path.join(d, f"{lib}.kicad_sym"), "w") as f:
            f.write("(kicad_symbol_lib (version 20220914) (generator kicad_symbol_editor)\n")
            f.write("".join(texts))
            f.write(")\n")


def fetch_model(rel):
    dst = os.path.join(MODEL_CACHE, rel)
    if os.path.exists(dst) and os.path.getsize(dst) > 1000:
        return dst
    os.makedirs(os.path.dirname(dst), exist_ok=True)
    url = MODEL_URL + rel
    r = subprocess.run(["curl", "-sS", "-f", "-L", "-o", dst, url], capture_output=True, text=True)
    if r.returncode != 0:  # fall back to the GitLab master (lazy blob fetch)
        with open(dst, "wb") as f:
            r = subprocess.run(["git", "-C", P3D_GIT, "show", "HEAD:" + rel], stdout=f, stderr=subprocess.PIPE)
    if r.returncode != 0:
        print("  !! model download failed:", rel, r.stderr.strip(), file=sys.stderr)
        return None
    return dst


def copy_footprint(lib, fp_name, src, model_rel):
    srclib, srcname = src.split(":", 1)
    txt = open(os.path.join(KICAD_FP, srclib + ".pretty", srcname + ".kicad_mod")).read()
    txt = re.sub(r'^\(footprint "[^"]+"', f'(footprint "{fp_name}"', txt, count=1)
    txt = re.sub(r'\(fp_text value "[^"]+"', f'(fp_text value "{fp_name}"', txt, count=1)
    # drop original model blocks, then add ours
    txt = re.sub(r'\n\s*\(model "[^"]*"(?:\s*\((?:offset|scale|rotate) \(xyz [^)]*\)\))*\s*\)', "", txt)
    if model_rel:
        path = fetch_model(model_rel)
        if path:
            d3 = os.path.join(ROOT, lib, f"{lib}.3dshapes")
            os.makedirs(d3, exist_ok=True)
            out_name = os.path.basename(model_rel)
            shutil.copyfile(path, os.path.join(d3, out_name))
            model = (f'  (model "${{KIPRJMOD}}/../KiCad_Libs/{lib}/{lib}.3dshapes/{out_name}"\n'
                     f"    (offset (xyz 0 0 0))\n    (scale (xyz 1 1 1))\n    (rotate (xyz 0 0 0))\n  )\n")
            txt = txt.rstrip()
            assert txt.endswith(")")
            txt = txt[:-1].rstrip() + "\n" + model + ")\n"
    if fp_name.startswith("PQFN-8_3.3x3.3mm"):
        # NexFET land pattern: the drain leads are unnamed copper pads overlapping the tab -> make them pad 5 (drain)
        txt = re.sub(r'\(pad "" (smd roundrect [^\n]*"F\.Cu")', r'(pad "5" \1', txt)
    d = os.path.join(ROOT, lib, f"{lib}.pretty")
    os.makedirs(d, exist_ok=True)
    with open(os.path.join(d, fp_name + ".kicad_mod"), "w") as f:
        f.write(txt)


def custom_pad(lib, name, w, h):
    txt = f"""(footprint "{name}" (version 20221018) (generator pcbnew)
  (layer "F.Cu")
  (descr "Solder pad {w}x{h}mm for wires (battery / motor leads)")
  (tags "solder pad wire")
  (attr smd)
  (fp_text reference "REF**" (at 0 {-(h / 2 + 1.2):.2f}) (layer "F.SilkS")
    (effects (font (size 0.8 0.8) (thickness 0.12)))
  )
  (fp_text value "{name}" (at 0 {h / 2 + 1.2:.2f}) (layer "F.Fab")
    (effects (font (size 0.8 0.8) (thickness 0.12)))
  )
  (fp_rect (start {-w / 2 - 0.25:.2f} {-h / 2 - 0.25:.2f}) (end {w / 2 + 0.25:.2f} {h / 2 + 0.25:.2f})
    (stroke (width 0.05) (type default)) (fill none) (layer "F.CrtYd"))
  (pad "1" smd roundrect (at 0 0) (size {w} {h}) (layers "F.Cu" "F.Mask") (roundrect_rratio 0.1))
)
"""
    d = os.path.join(ROOT, lib, f"{lib}.pretty")
    os.makedirs(d, exist_ok=True)
    open(os.path.join(d, name + ".kicad_mod"), "w").write(txt)


def build_footprints():
    for part in P.PARTS.values():
        if part.fp and part.fp_src:
            copy_footprint(part.lib, part.fp, part.fp_src, part.model)
    for (_, name), (lib, src, model) in P.GENERIC_FP.items():
        copy_footprint(lib, name, src, model)
    for name, (lib, w, h) in P.CUSTOM_FP.items():
        custom_pad(lib, name, w, h)


def build_docs():
    libs = {}
    for part in P.PARTS.values():
        if part.fields.get("MPN"):
            libs.setdefault(part.lib, []).append(part)
    for lib, plist in libs.items():
        d = os.path.join(ROOT, lib, "datasheet")
        os.makedirs(d, exist_ok=True)
        lines = [f"# {lib} datasheets\n", "| Part | Manufacturer | MPN | Datasheet |", "|---|---|---|---|"]
        for part in sorted(plist, key=lambda x: x.name):
            f = part.fields
            lines.append(f"| {part.name} | {f.get('Manufacturer', '')} | {f.get('MPN', '')} | {f.get('Datasheet', '')} |")
        open(os.path.join(d, "README.md"), "w").write("\n".join(lines) + "\n")
    for pdf, lib in (("RTC6705-RichWave.pdf", "eRFModule"), ("RFPA5542-Qorvo.pdf", "eAmplifier")):
        src = os.path.join(OPENVTX_DOCS, pdf)
        if os.path.exists(src):
            os.makedirs(os.path.join(ROOT, lib, "datasheet"), exist_ok=True)
            shutil.copyfile(src, os.path.join(ROOT, lib, "datasheet", pdf))
    for lib in os.listdir(ROOT):
        if os.path.isdir(os.path.join(ROOT, lib)):
            open(os.path.join(ROOT, lib, ".gitignore"), "w").write("*.bak\n*-bak\n*.lck\n~*\n_autosave-*\n")


def build_all(write=True):
    build_symbols()
    if write:
        write_symbol_libs()
        build_footprints()
        build_docs()


if __name__ == "__main__":
    build_all()
    print("libraries written to", ROOT)

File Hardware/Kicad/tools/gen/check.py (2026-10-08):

"""Validate a generated project: export the netlist with kicad-cli and compare KiCad's connectivity
with the intended connectivity (as partitions of (ref, pin)), plus basic electrical-rule checks."""
import importlib
import os
import tempfile
import subprocess
import sys

import libbuild
from sexp import parse, find, find_all

sys.dont_write_bytecode = True


def kicad_netlist(proj_dir, name):
    out = os.path.join(tempfile.gettempdir(), f"{name}.net")
    subprocess.run(["kicad-cli", "sch", "export", "netlist", "--format", "kicadsexpr", "-o", out,
                    f"{proj_dir}/{name}.kicad_sch"], check=True, capture_output=True)
    tree = parse(open(out).read())
    nets = {}
    for n in find_all(find(tree, "nets"), "net"):
        nm = find(n, "name")[1]
        nodes = frozenset((find(x, "ref")[1], find(x, "pin")[1]) for x in find_all(n, "node"))
        nets[nm] = nodes
    comps = {find(c, "ref")[1]: find(c, "value")[1] for c in find_all(find(tree, "components"), "comp")}
    return nets, comps


def expected(B):
    groups = {}
    types = {}
    for s in B.sheets:
        for path, iname, base, portmap in B.sheet_paths(s):
            for it in s.items:
                if it.ref_prefix.startswith("#"):
                    continue
                ref = it.refs[path]
                for num, net in it.pin_net().items():
                    types[(ref, num)] = it.sym["types"].get(num)
                    if net == "NC":
                        key = ("NC", ref, num)
                    elif net in libbuild.POWER_NETS or not s.instances or net in s.force_global:
                        key = net
                    elif net in s.ports:
                        key = portmap[net]
                    else:
                        key = (iname, net)
                    groups.setdefault(key, set()).add((ref, num))
    return groups, types


def run(mod, proj_dir):
    m = importlib.import_module(mod)
    B = m.B
    B.annotate()
    nets, comps = kicad_netlist(proj_dir, B.name)
    exp, types = expected(B)
    ok = True
    actual_parts = {}
    for nm, nodes in nets.items():
        for node in nodes:
            actual_parts[node] = nm
    # every intended net must be exactly one KiCad net
    for key, nodes in exp.items():
        if isinstance(key, tuple) and key[0] == "NC":
            continue
        names = {actual_parts.get(n) for n in nodes}
        if len(names) != 1 or None in names:
            ok = False
            print(f"  SPLIT/MISSING net {key}: {names}")
            continue
        nm = names.pop()
        if set(nets[nm]) != set(nodes):
            extra = set(nets[nm]) - set(nodes)
            ok = False
            print(f"  MERGED net {key} with {sorted(extra)[:6]}")
    # single-pin nets (excluding NC flags and test points)
    for key, nodes in exp.items():
        if isinstance(key, tuple) and key[0] == "NC":
            continue
        if len(nodes) == 1:
            ref, pin = next(iter(nodes))
            if not ref.startswith("TP"):
                print(f"  WARN single-pin net {key}: {ref}.{pin}")
    # driver check: nets with input pins but no output/bidir/passive/power_out source
    for key, nodes in exp.items():
        if isinstance(key, tuple) and key[0] == "NC":
            continue
        t = [types[n] for n in nodes]
        if "input" in t and not any(x in ("output", "bidirectional", "tri_state", "passive", "power_out", "open_collector") for x in t):
            print(f"  WARN input-only net {key}: {sorted(nodes)}")
        if t.count("output") + t.count("power_out") > 1 and key not in libbuild.POWER_NETS:
            print(f"  WARN multiple outputs on {key}: {sorted(n for n in nodes if types[n] in ('output', 'power_out'))}")
    n_comp = len([c for c in comps if not c.startswith("#")])
    print(f"{B.name}: {n_comp} components, {len(nets)} nets -> {'CONNECTIVITY OK' if ok else 'ERRORS'}")
    return ok


if __name__ == "__main__":
    libbuild.build_all(write=False)
    import os
    base = os.path.abspath(os.path.join(os.path.dirname(__file__), "..", ".."))
    good = True
    for mod in sys.argv[1:] or ["fcv00", "escv00", "rxv00", "vtxv00"]:
        name = mod.upper()
        good &= run(mod, os.path.join(base, name))
    sys.exit(0 if good else 1)

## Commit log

2026-07-30 corrected kicad libraries import
    [FCV00.kicad_pcb, FCV00.kicad_sch]
2026-10-08 prima versione pcb
    [ESCV00.kicad_pcb, ESCV00.kicad_sch, ESCV00_BOM.csv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]
2026-10-08 librerie: KiCad_Libs_ToAdd e script bring/merge verso L2-Hardware/Kicad_Libs
2026-10-08 bring_libs: sostituisce la junction KiCad_Libs vecchia o rotta
2026-10-08 version upgrade
    [ESCV00.kicad_pcb, ESCV00.kicad_sch, FCV00.kicad_pcb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]
